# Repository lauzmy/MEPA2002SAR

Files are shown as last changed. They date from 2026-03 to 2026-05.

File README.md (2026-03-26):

# MEPA2002SAR

A ROS 2 + Gazebo Sim workspace that launches simulation, bridges ROS↔Gazebo topics, and runs a small application node that publishes `cmd_vel` for a diff‑drive robot.

## Quickstart
**Prereqs:** Docker Engine with Compose plugin and `make`.

1. Build and start the container:
   - `make build`
   - `make up`
   - `make shell`
2. Build the workspace in the container:
   - `colcon build --cmake-args -DBUILD_TESTING=ON`
   - `source install/setup.sh`
3. Launch the diff‑drive demo:
   - `ros2 launch ros_gz_bringup diff_drive.launch.py`

**Optional GUI tools (RViz/RQt):**
- `make build DESKTOP=1`
- `make x11`
- `make recreate`

## Documentation
- [Architecture](Architecture.md)
- [Setup & Build](Setup.md)
- [Bringup & Launch](Bringup.md)
- [Workspace Layout](Workspace-Layout.md)
- [Packages](Packages.md)
- [Simulation Assets](Simulation-Assets.md)
- [Development Guide](Development-Guide.md)

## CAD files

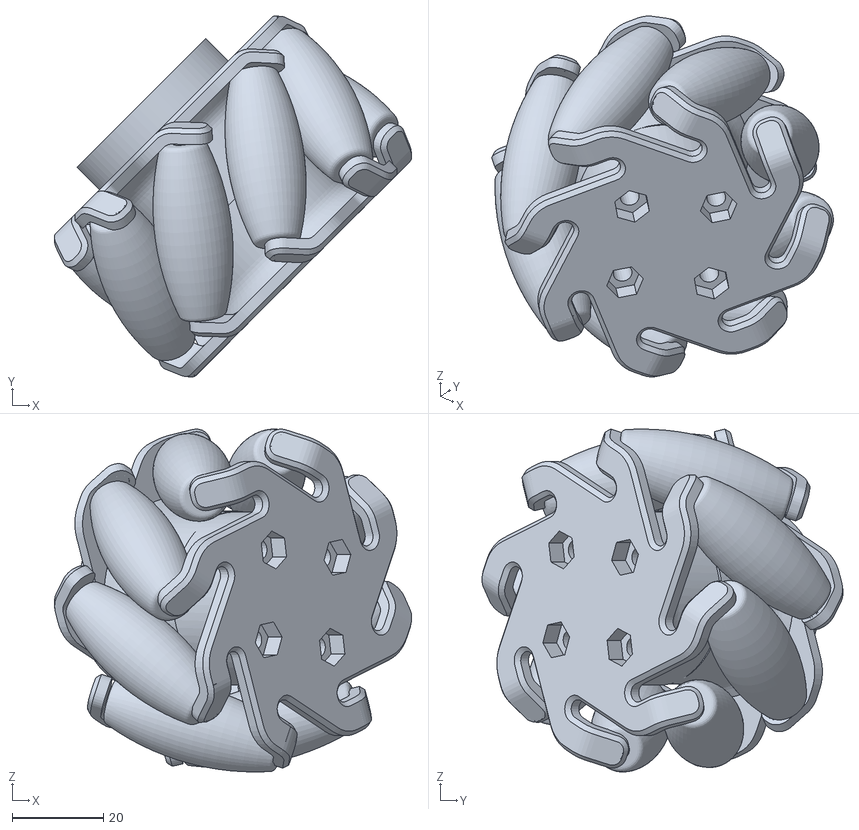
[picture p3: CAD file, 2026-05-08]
src/GregorURDF/meshes/Mecanum-wheel-RR.stl
78.5 x 79.3 x 75.3

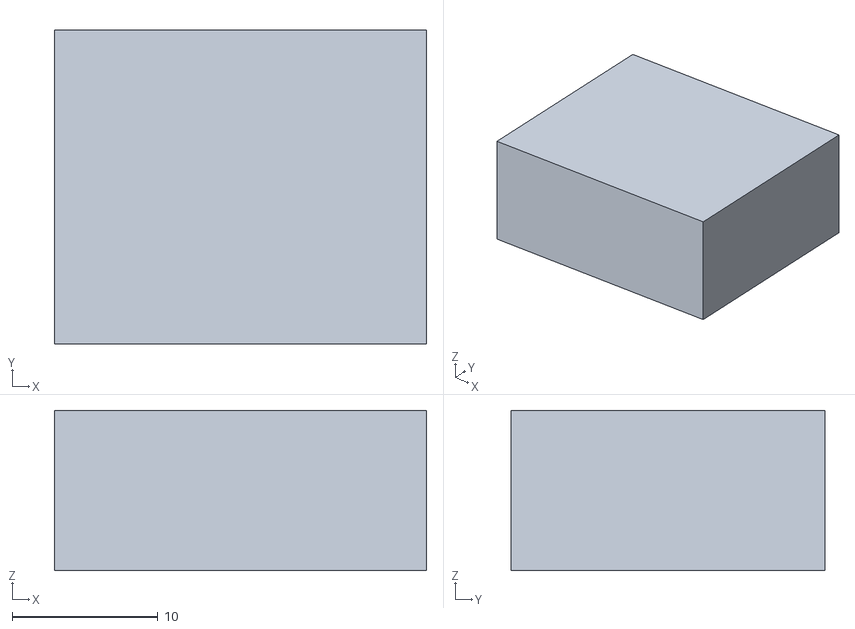
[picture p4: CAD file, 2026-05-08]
src/GregorURDF/meshes/Avstands-sensor-venstre.stl
25.5 x 21.5 x 11.0

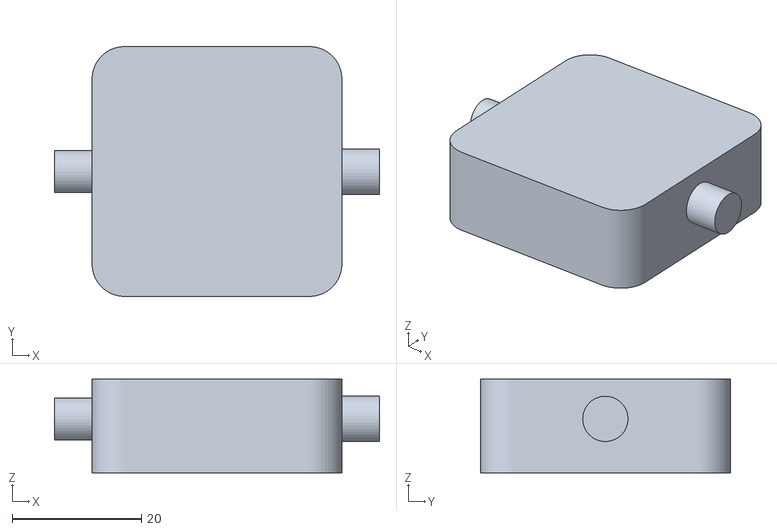
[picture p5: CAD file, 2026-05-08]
src/GregorURDF/meshes/LiDAR-Mount.stl
50.2 x 38.6 x 14.5

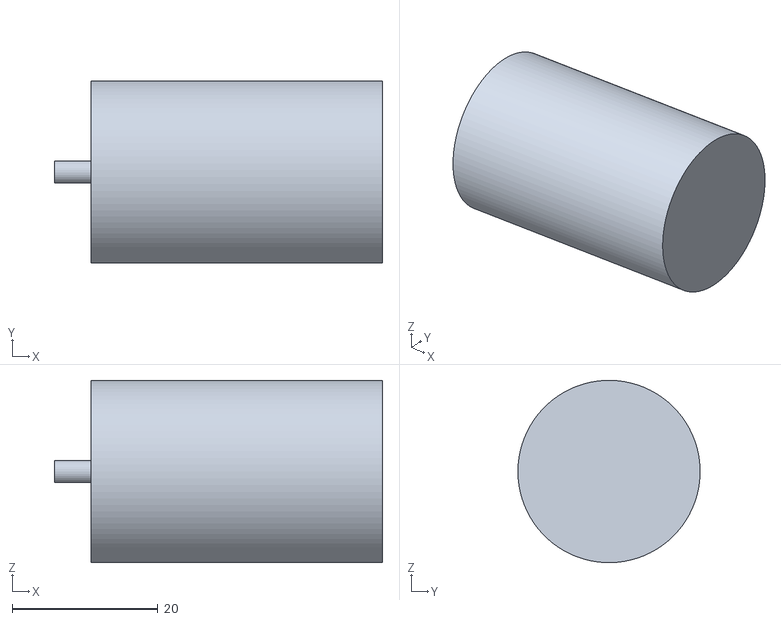
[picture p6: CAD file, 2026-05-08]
src/GregorURDF/meshes/Motor-RR.stl
45.0 x 25.0 x 25.0

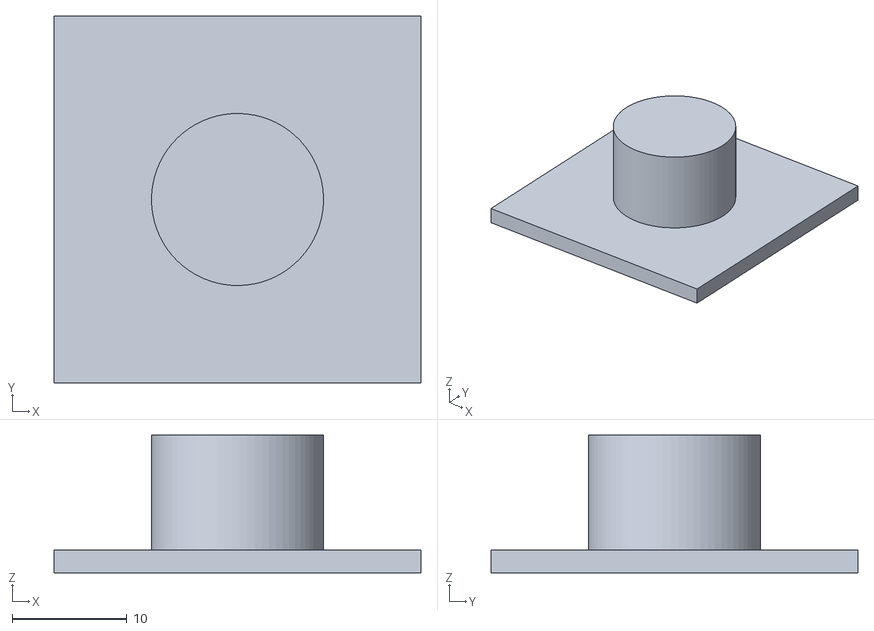
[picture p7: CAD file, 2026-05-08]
src/GregorURDF/meshes/RGB-Camera.stl
32.0 x 32.0 x 12.0

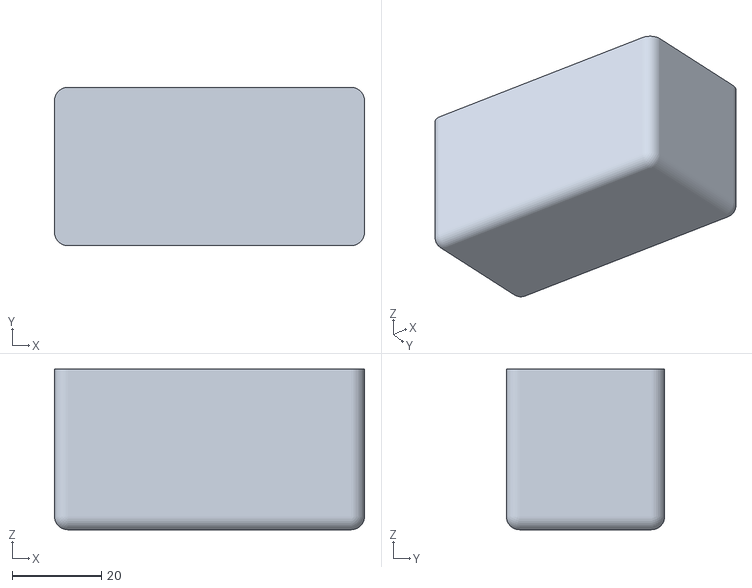
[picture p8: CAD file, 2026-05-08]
src/GregorURDF/meshes/Battery.stl
69.5 x 35.5 x 36.0

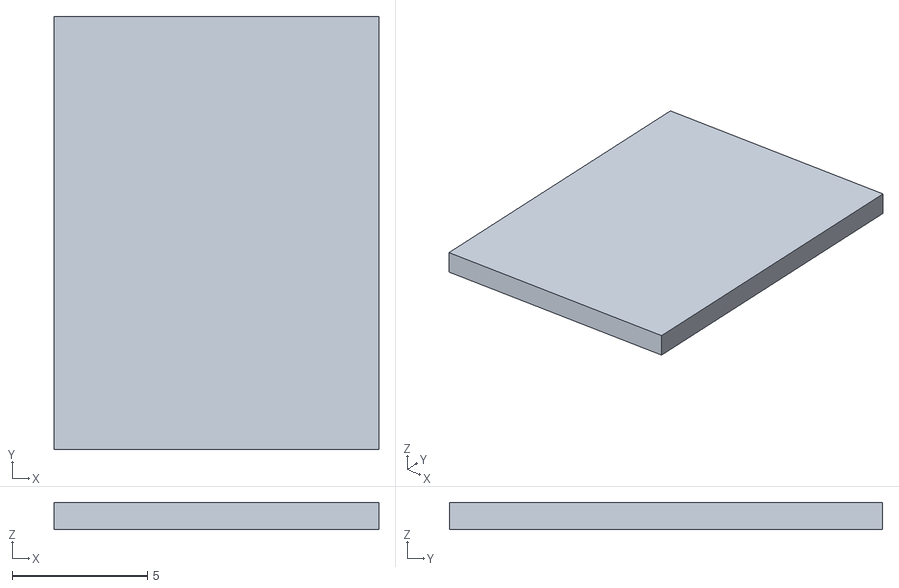
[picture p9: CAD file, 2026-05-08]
src/GregorURDF/meshes/IMU.stl
12.0 x 16.0 x 1.00

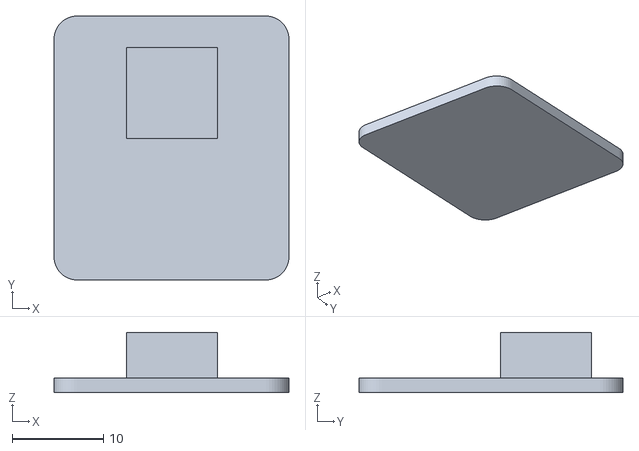
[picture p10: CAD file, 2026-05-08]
src/GregorURDF/meshes/Thermal-camera.stl
25.8 x 28.9 x 6.58

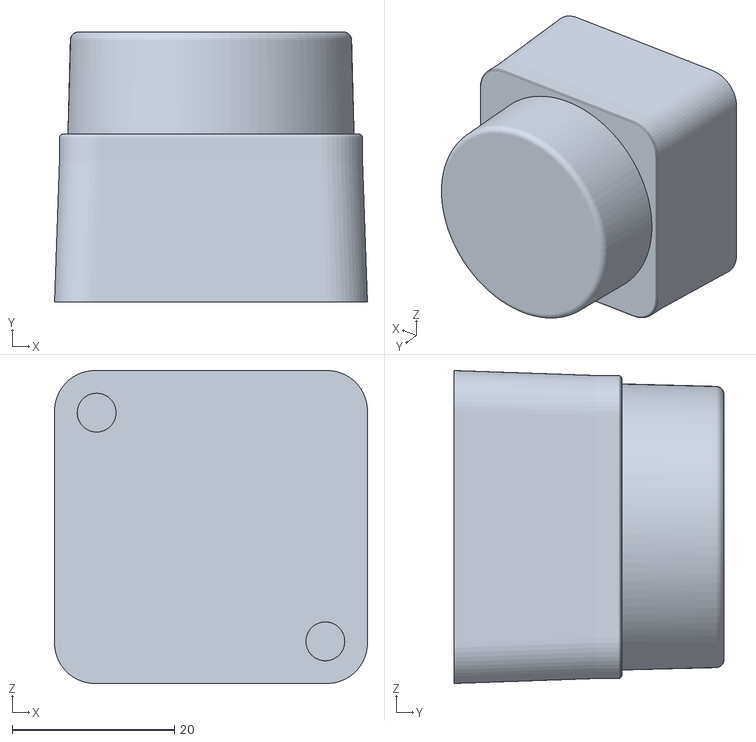
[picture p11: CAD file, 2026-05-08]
src/GregorURDF/meshes/LD06_LiDAR.stl
38.6 x 33.3 x 38.6

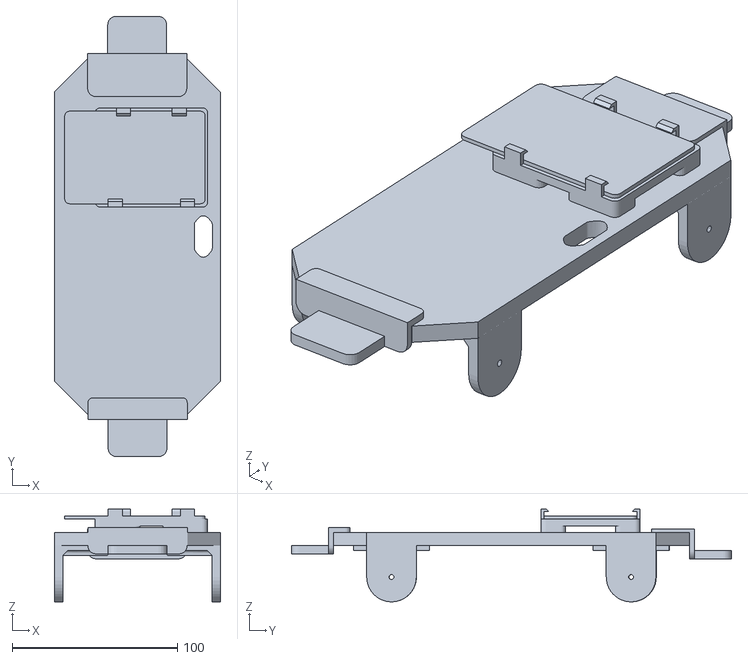
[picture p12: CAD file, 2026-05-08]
src/GregorURDF/meshes/Chassie.stl
100.4 x 266.1 x 56.0

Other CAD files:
src/GregorURDF/meshes/Avstands-sensor-fremme.stl
src/GregorURDF/meshes/Avstands-sensor-bak.stl
src/GregorURDF/meshes/Upper-Level.stl

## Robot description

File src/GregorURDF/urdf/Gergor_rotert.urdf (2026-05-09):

<?xml version='1.0' encoding='utf-8'?>
<robot name="Gergor">
    <link name="Upper-Level">
        <inertial>
            <origin xyz="0.0023967975342630166 -0.0013615270577073536 0.03779211299373483" rpy="0.0 -0.0 0.0" />
            <mass value="0.13651212208139799" />
            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
        </inertial>
        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
    </link>
    <link name="Battery">
        <inertial>
            <origin xyz="4.458219052816403e-09 3.6607721659760727e-09 0.017923845987170874" rpy="0.0 -0.0 0.0" />
            <mass value="0.09697089693767996" />
            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
        </inertial>
        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
    </link>
    <link name="RGB-Camera">
        <inertial>
            <origin xyz="0.003779157752404263 -0.016000000000072616 -0.016000001679936388" rpy="0.0 -0.0 0.0" />
            <mass value="0.00705801985514185" />
            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
        </inertial>
        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
    </link>
    <link name="Avstands-sensor-fremme">
        <inertial>
            <origin xyz="-0.010750000953176712 -0.012750001333232112 -0.0054999999999998566" rpy="0.0 -0.0 0.0" />
            <mass value="0.011156887500000002" />
            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
        </inertial>
        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
    </link>
    <link name="Chassie">
        <inertial>
            <origin xyz="0.0005701965615616624 -0.0010046150242972978 0.0033131328971587404" rpy="0.0 0.0 0.0" />
            <mass value="0.29216485565837275" />
            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
        </inertial>
        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
    </link>
    <link name="Avstands-sensor-bak">
        <inertial>
            <origin xyz="0.010749999869614797 -0.012750001724095177 0.0054999999999998566" rpy="0.0 -0.0 0.0" />
            <mass value="0.011156887500000002" />
            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
        </inertial>
        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
    </link>
    <link name="Thermal-camera">
        <inertial>
            <origin xyz="0.0017759347881090104 -0.012620736087732034 0.01036523496622269" rpy="0.0 -0.0 0.0" />
            <mass value="0.0030870822826619742" />
            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
        </inertial>
        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
    </link>
    <link name="Avstands-sensor-venstre">
        <inertial>
            <origin xyz="0.012750004398614394 -0.010750002155754865 -0.005499997674649775" rpy="0.0 -0.0 0.0" />
            <mass value="0.0111568875" />
            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
        </inertial>
        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
    </link>
    <link name="Motor-FR">
        <inertial>
            <origin xyz="1.7319479184152443e-16 0.02494272447716412 -9.573994930178742e-10" rpy="0.0 -0.0 0.0" />
            <mass value="0.15441088816550527" />
            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
        </inertial>
        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
    </link>
    <link name="LD06_LiDAR">
        <inertial>
            <origin xyz="3.6113848578267493e-09 4.421719479175135e-09 0.015204879071300024" rpy="0.0 -0.0 0.0" />
            <mass value="0.07569091272999597" />
            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
        </inertial>
        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
    </link>
    <link name="IMU">
        <inertial>
            <origin xyz="4.45821904060395e-09 -3.3031442930875345e-09 0.000500000000000096" rpy="0.0 -0.0 0.0" />
            <mass value="0.0003552000152170653" />
            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
        </inertial>
        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
    </link>
    <link name="Mecanum-wheel-FL">
        <inertial>
            <origin xyz="-0.000322364933043513 -0.026544464448392563 0.00017061718757419798" rpy="0.0 -0.0 0.0" />
            <mass value="0.1511892944710378" />
            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
        </inertial>
        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
    </link>
    <link name="LiDAR-Mount">
        <inertial>
            <origin xyz="-0.0010789646894884797 -3.2563265073845916e-05 -2.067058956080295e-05" rpy="9.767397155917488e-50 -0.0 -4.861730685829017e-63" />
            <mass value="0.025423989422360332" />
            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
        </inertial>
        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
    </link>
    <link name="Mecanum-wheel-RL">
        <inertial>
            <origin xyz="-0.0003223649330433842 0.026544460526042205 -0.0001706147432024441" rpy="0.0 -0.0 0.0" />
            <mass value="0.1511892944710378" />
            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
        </inertial>
        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
    </link>
    <link name="Mecanum-wheel-RR">
        <inertial>
            <origin xyz="-0.00032236493304357074 -0.026544461164959225 0.00017061624033781086" rpy="0.0 -0.0 0.0" />
            <mass value="0.1511892944710378" />
            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
        </inertial>
        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
    </link>
    <link name="Mecanum-wheel-FR">
        <inertial>
            <origin xyz="-0.00032236493304340643 0.026544461164959312 -0.00017061407967208453" rpy="0.0 -0.0 0.0" />
            <mass value="0.1511892944710378" />
            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
        </inertial>
        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
    </link>
    <link name="Avstands-sensor-høyre">
        <inertial>
            <origin xyz="-0.012750003968667767 0.01075000376223434 -0.005499999999999901" rpy="0.0 -0.0 0.0" />
            <mass value="0.0111568875" />
            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
        </inertial>
        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
    </link>
    <link name="Motor-RL">
        <inertial>
            <origin xyz="-8.881784197001253e-18 0.02494272511608105 -2.938676235686444e-10" rpy="0.0 -0.0 0.0" />
            <mass value="0.15441088816550527" />
            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
        </inertial>
        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
    </link>
    <link name="Motor-RR">
        <inertial>
            <origin xyz="1.2878587085651815e-16 -0.024942724477164085 -1.203269146543562e-09" rpy="0.0 -0.0 0.0" />
            <mass value="0.15441088816550527" />
            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
        </inertial>
        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
    </link>
    <link name="Motor-FL">
        <inertial>
            <origin xyz="1.1990408665951691e-16 0.02494272119373083 2.1505034375479682e-09" rpy="0.0 -0.0 0.0" />
            <mass value="0.15441088816550527" />
            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
        </inertial>
        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
    </link>
    <joint name="Chassie_Rigid-1" type="fixed">
        <origin xyz="0.00015423000372526423 -0.007561000130385147 -1.4210854715202004e-16" rpy="3.141592653589793 6.1584619237316516e-33 -1.5707963267948966" />
        <parent link="Chassie" />
        <child link="Battery" />
    </joint>
    <joint name="Chassie_Rigid-2" type="fixed">
        <origin xyz="0.00015423000372526423 -0.007561000130385147 0.007999999999999856" rpy="-3.2526065174564526e-19 6.1584619237316516e-33 -1.5707963267948966" />
        <parent link="Chassie" />
        <child link="Upper-Level" />
    </joint>
    <joint name="Upper-Level_Revolute-3" type="continuous">
        <origin xyz="4.479000000000011e-05 -3.5119999999999996e-05 0.08375145" rpy="-1.6930901125533616e-15 -1.5707963267948966 0" />
        <parent link="Upper-Level" />
        <child link="LiDAR-Mount" />
        <axis xyz="9.398538128609942e-32 -0.9999999999999996 -1.6930901125533608e-15" />
    </joint>
    <joint name="LiDAR-Mount_Rigid-4" type="fixed">
        <origin xyz="0.006150000000000003 3.469446951953614e-20 -2.1069999999999702e-05" rpy="1.102916357619544e-47 1.570796326794895 0" />
        <parent link="LiDAR-Mount" />
        <child link="LD06_LiDAR" />
    </joint>
    <joint name="Upper-Level_Rigid-5" type="fixed">
        <origin xyz="0.057249999999999995 -0.03049246 0.056499999999999995" rpy="1.570796326794901 -0.0 0.0" />
        <parent link="Upper-Level" />
        <child link="RGB-Camera" />
    </joint>
    <joint name="Upper-Level_Rigid-6" type="fixed">
        <origin xyz="0.057249999999999995 0.02750754 0.056499999999999995" rpy="1.5707963267948966 -0.0 0.0" />
        <parent link="Upper-Level" />
        <child link="Thermal-camera" />
    </joint>
    <joint name="Upper-Level_Rigid-7" type="fixed">
        <origin xyz="0.0 0.0 0.04035000000000001" rpy="0.0 -0.0 0.0" />
        <parent link="Upper-Level" />
        <child link="IMU" />
    </joint>
    <joint name="Upper-Level_Rigid-8" type="fixed">
        <origin xyz="-0.012 0.085 -0.014802099999999997" rpy="0.0 -0.0 0.0" />
        <parent link="Upper-Level" />
        <child link="Avstands-sensor-venstre" />
    </joint>
    <joint name="Chassie_Rigid-9" type="fixed">
        <origin xyz="0.013000710003725262 -0.14062201013038508 -0.005000000000000142" rpy="-3.2526065174564526e-19 6.1584619237316516e-33 -1.5707963267948966" />
        <parent link="Chassie" />
        <child link="Avstands-sensor-fremme" />
    </joint>
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

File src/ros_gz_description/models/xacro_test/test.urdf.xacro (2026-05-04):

<?xml version="1.0"?>
<robot name="rrbot" xmlns:xacro="http://www.ros.org/wiki/xacro" xmlns:gz="http://gazebosim.org/schema">


  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
  <xacro:property name="pi_const" value="3.141592653589793"/>

  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
  <xacro:property name="a" value="0.22"/>
  <xacro:property name="b" value="0.1"/>
  <xacro:property name="c" value="0.1"/>

  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
  <xacro:property name="r" value="0.0375"/>
  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
  <xacro:property name="d" value="0.043"/>


  <xacro:property name="s1" value="${b/2+r}"/>
  <xacro:property name="s2" value="${2*r}"/>
  <xacro:property name="s3" value="${2*r}"/>
  <xacro:property name="s4" value="${c/2+d/2}"/>
  <xacro:property name="s5" value="${b/2}"/>


  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
  <xacro:property name="d1" value="2710.0"/>
  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
  <xacro:property name="d2" value="2710.0"/>
  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
  <xacro:property name="d3" value="2710.0"/>

  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
  <xacro:property name="m1" value="${d1*a*b*c}"/>
  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
  <xacro:property name="m2" value="${d2*pi_const*r*r*d}"/>
  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
  <xacro:property name="m3" value="${d3*4/3*pi_const*r*r*r}"/>

  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
  <xacro:property name="Ix_body" value="${m1*(b*b+c*c)/12}"/>
  <xacro:property name="Iy_body" value="${m1*(a*a+c*c)/12}"/>
  <xacro:property name="Iz_body" value="${m1*(a*a+b*b)/12}"/>

  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
  <xacro:property name="Iz_wheel" value="${m2*r*r/2}"/>
  <xacro:property name="I_wheel" value="${m2*(3*r*r + d*d)/12}"/>



  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
  <xacro:macro name="inertial_body">
    <inertial>
    <origin rpy=" 0 0 0" xyz="0 0 ${s1}"/>
    <mass value="${m1}"/>
    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
    </inertial>
  </xacro:macro>

  <xacro:macro name="inertial_wheel">
    <inertial>
    <origin rpy="1.570795 0 0" xyz="0 0 0"/>
    <mass value="${m2}"/>
    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
    </inertial>
  </xacro:macro>


  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

  <link name="base_footprint"/>
  
  <joint name="body_link_joint" type="fixed">
    <parent link="base_footprint"/>
    <child link="body_link"/>
  </joint>


  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
  <link name="body_link">
    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  

    <xacro:inertial_body/>
  </link>

  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
  <joint name="rear_right_wheel_joint" type="continuous">
    <parent link="body_link"/>
    <child link="rear_right_wheel_link"/>
    <origin xyz="${-s2} ${-s4} ${r}" rpy="0 0 0"/>
    <axis xyz="0 1 0"/>
    <limit effort="50000" velocity="10"/>
    <dynamics damping="1.0" friction="1.0"/>
  </joint>

  <link name="rear_right_wheel_link">
    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

    <xacro:inertial_wheel/>
  </link>

  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
  <joint name="rear_left_wheel_joint" type="continuous">
    <parent link="body_link"/>
    <child link="rear_left_wheel_link"/>
    <origin xyz="${-s2} ${s4} ${r}" rpy="0 0 0"/>
    <axis xyz="0 1 0"/>
    <limit effort="50000" velocity="10"/>
    <dynamics damping="1.0" friction="1.0"/>
  </joint>

  <link name="rear_left_wheel_link">
    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

    <xacro:inertial_wheel/>
  </link>

  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
  <joint name="front_right_wheel_joint" type="continuous">
    <parent link="body_link"/>
    <child link="front_right_wheel_link"/>
    <origin xyz="${s2} ${-s4} ${r}" rpy="0 0 0"/>
    <axis xyz="0 1 0"/>
    <limit effort="50000" velocity="10"/>
    <dynamics damping="1.0" friction="1.0"/>
  </joint>

  <link name="front_right_wheel_link">
    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

    <xacro:inertial_wheel/>
  </link>

  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
  <joint name="front_left_wheel_joint" type="continuous">
    <parent link="body_link"/>
    <child link="front_left_wheel_link"/>
    <origin xyz="${s2} ${s4} ${r}" rpy="0 0 0"/>
    <axis xyz="0 1 0"/>
    <limit effort="50000" velocity="10"/>
    <dynamics damping="1.0" friction="1.0"/>
  </joint>

  <link name="front_left_wheel_link">
    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

    <xacro:inertial_wheel/>
  </link>


  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
  <joint name="lidar_joint" type="revolute">
    <parent link="body_link"/>
    <child link="lidar_hinge_link"/>
    <origin xyz="0 0 ${s1+s5}" rpy="0 0 0"/>
    <axis xyz="0 1 0"/> 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
    <limit lower="-0.785398" upper="0.785398" effort="10.0" velocity="5.0"/> 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
    <dynamics damping="0.1" friction="0.1"/>
  </joint>

  <link name="lidar_hinge_link">
    <inertial>
      <mass value="0.05"/>
      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
    </inertial>
  </link>
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

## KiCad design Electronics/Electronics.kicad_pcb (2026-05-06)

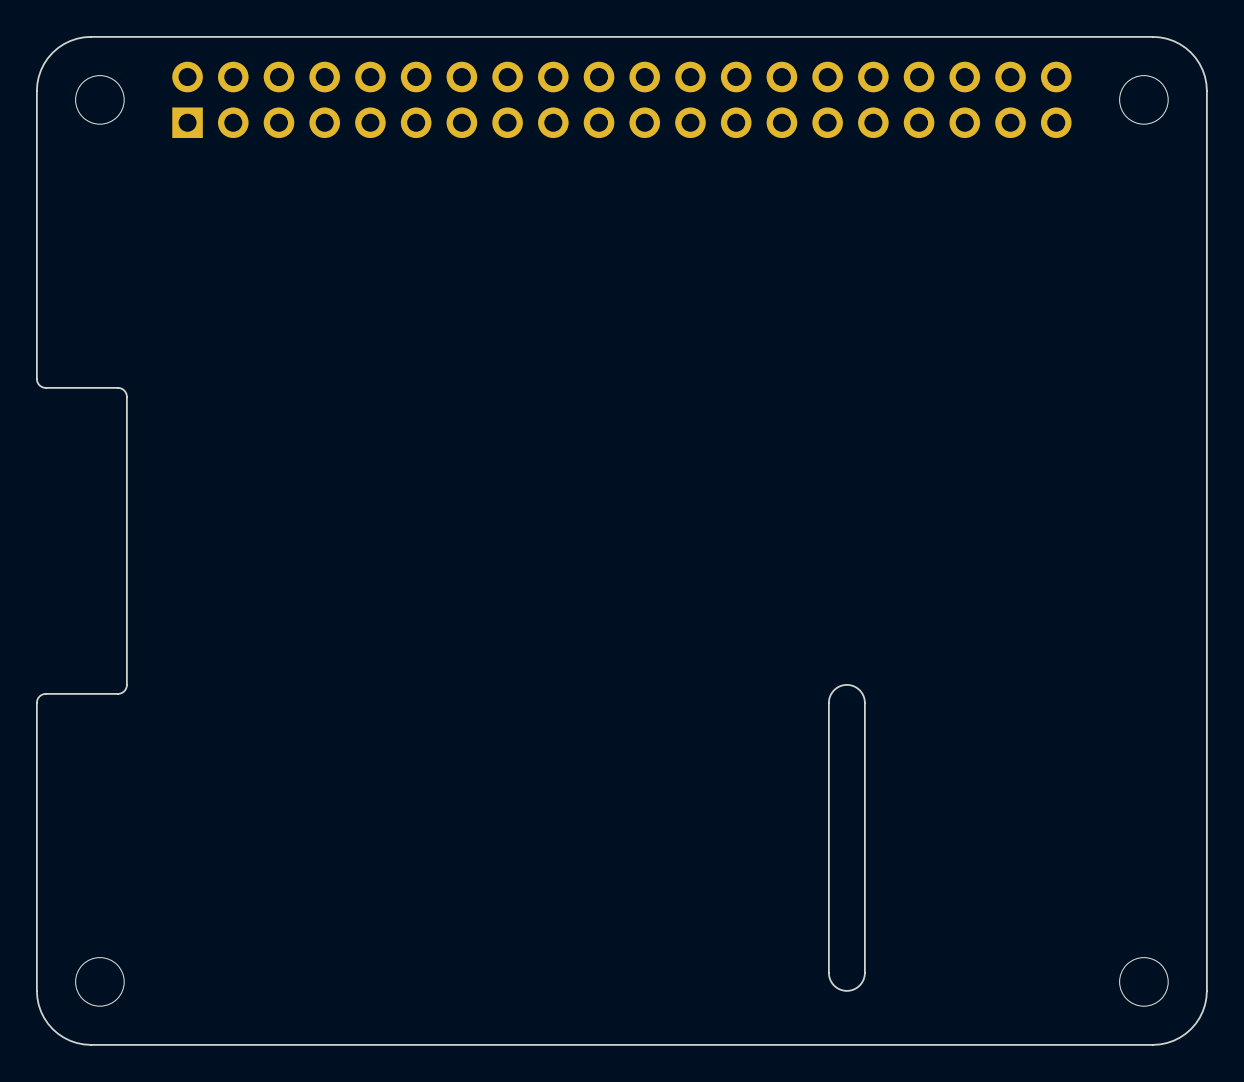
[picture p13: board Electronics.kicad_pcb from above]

Board: 2 copper layers, 65.0 x 56.0 mm, 5 parts (1 on the bottom side), 3 nets, no tracks yet.

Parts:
J1: GPIO; PinSocket_2x20_P2.54mm_Vertical
MH1, MH2, MH3, MH4: MountingHole_2.7mm_M2.5

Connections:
+3V3: J1.1, J1.17
+5V: J1.2, J1.4
GND: J1.6, J1.9, J1.14, J1.20, J1.25, J1.30, J1.34, J1.39

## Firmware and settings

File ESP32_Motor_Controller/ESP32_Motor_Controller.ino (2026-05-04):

/*
 * ESP32 Motor Controller
 *
 * Single-loop architecture.
 * ISRs write volatile period data; loop() reads, filters, and dispatches.
 *
 * Protocol (8 bytes, unchanged from v1):
 *   Command:  [START=0x55][CMD][M1_SPD][M2_SPD][M3_SPD][M4_SPD][DIRS][CRC8]
 *   Response: [START=0x55][STATUS][M1_RPM][M2_RPM][M3_RPM][M4_RPM][VBATT][CRC8]
 *
 *   CRC-8/MAXIM covers bytes 0-6.
 *   DIRS = [0][0][0][0][M4_DIR][M3_DIR][M2_DIR][M1_DIR]
 *   VBATT = battery voltage scaled 0-255 (0-16V)
 *
 * Commands:
 *   0x01: Set all motors (speed + direction)
 *   0x02: Stop all motors
 *   0xFF: Ping / request telemetry
 *
 * Status:
 *   0x00: OK
 *   0x01: Invalid command
 */

#include <HardwareSerial.h>

// ============================================================================
// CONFIGURATION
// ============================================================================

// UART — using UART0 (USB via onboard USB-to-serial chip)
// Switch UART_USE_USB to 0 and set UART_TX_PIN/RX_PIN to use hardware pins instead.
#define UART_USE_USB  1          // 1 = Serial (USB/UART0), 0 = UART2 (pins 16/17)
#define UART_TX_PIN   17         // only used when UART_USE_USB = 0
#define UART_RX_PIN   16         // only used when UART_USE_USB = 0
#define UART_BAUDRATE 921600

// Battery ADC
#define VOLTAGE_PIN           13
#define VOLTAGE_DIVIDER_RATIO 0.17543859649123f  // 100k / (470k + 100k)
#define ADC_VREF              3.3f
#define ADC_CAL_FACTOR        (16.0f / 10.0f)    // empirical non-linearity correction

// Motor PWM
#define PWM_FREQ       20000
#define PWM_RESOLUTION 10      // 10-bit → 0-1023
#define PWM_MAX        1023

// Encoder
#define PPR                 270
#define FEEDBACK_TIMEOUT_US 6000                    // RPM → 0 if no pulse within this window
#define DEBOUNCE_MIN_US     50                      // ignore pulses shorter than this
#define DEBOUNCE_MAX_US     ((uint32_t)(FEEDBACK_TIMEOUT_US * 4))

// EMA filter (0.0–1.0: higher = faster response, more noise)
#define EMA_ALPHA 0.4f

// Comms watchdog — stop motors if no valid packet received within this window.
// Must be set to at least 3-5× your control loop's inter-packet interval.
// e.g. 100 Hz loop (10 ms/packet) → 50 ms minimum; 50 Hz (20 ms) → 100 ms.
// Too short and the watchdog fires between every packet, keeping motors stopped.
#define WATCHDOG_MS 200

// Protocol
#define PACKET_SIZE 8
#define START_BYTE  0x55

// Commands
#define CMD_SET_ALL  0x01
#define CMD_STOP_ALL 0x02
#define CMD_PING     0xFF

// Status bytes
#define STATUS_OK           0x00
#define STATUS_INVALID_CMD  0x01
#define STATUS_CHECKSUM_ERR 0x02

// ============================================================================
// MOTOR PIN MAP
// ============================================================================

struct MotorPins {
  int  dir_pin;
  int  pwm_pin;
  int  sig_pin;
  bool invert_dir;
};

const MotorPins MOTOR_CONFIG[4] = {
  {21, 22, 23, true },  // M1
  {18,  2, 19, false},  // M2
  {14, 12, 27, false},  // M3
  {25, 26, 33, true }   // M4
};

// ============================================================================
// MOTOR STATE
// ============================================================================

struct MotorState {
  volatile uint32_t last_rise_us;  // written by ISR
  volatile uint32_t period_us;     // written by ISR (latest raw period)
  float    ema_period_us;          // EMA-filtered period  (loop() only)
  uint8_t  rpm;                    // computed RPM         (loop() only)
};

MotorState motors[4];

// ============================================================================
// ENCODER ISRs
// No locks needed — loop() is the sole reader of ema_period_us / rpm,
// and 32-bit aligned volatile reads are atomic on Xtensa LX6.
// ============================================================================

void IRAM_ATTR motorISR0() {
  uint32_t now = micros();
  uint32_t p = now - motors[0].last_rise_us;
  if (p > DEBOUNCE_MIN_US && p < DEBOUNCE_MAX_US) motors[0].period_us = p;
  motors[0].last_rise_us = now;
}

void IRAM_ATTR motorISR1() {
  uint32_t now = micros();
  uint32_t p = now - motors[1].last_rise_us;
  if (p > DEBOUNCE_MIN_US && p < DEBOUNCE_MAX_US) motors[1].period_us = p;
  motors[1].last_rise_us = now;
}

void IRAM_ATTR motorISR2() {
  uint32_t now = micros();
  uint32_t p = now - motors[2].last_rise_us;
  if (p > DEBOUNCE_MIN_US && p < DEBOUNCE_MAX_US) motors[2].period_us = p;
  motors[2].last_rise_us = now;
}

void IRAM_ATTR motorISR3() {
  uint32_t now = micros();
  uint32_t p = now - motors[3].last_rise_us;
  if (p > DEBOUNCE_MIN_US && p < DEBOUNCE_MAX_US) motors[3].period_us = p;
  motors[3].last_rise_us = now;
}

// ============================================================================
// MOTOR CONTROL
// ============================================================================

void setMotor(int id, int speed, bool dir) {
  speed = constrain(speed, 0, 255);
  digitalWrite(MOTOR_CONFIG[id].dir_pin, dir ^ MOTOR_CONFIG[id].invert_dir);
  int duty = ((255 - speed) * PWM_MAX) / 255;  // inverted: 0 speed → full PWM_MAX (stopped)
  ledcWrite(MOTOR_CONFIG[id].pwm_pin, duty);
}

void stopAllMotors() {
  for (int i = 0; i < 4; i++) setMotor(i, 0, 0);
}

// ============================================================================
// CRC-8/MAXIM (polynomial 0x31)
// ============================================================================

uint8_t crc8(const uint8_t* data, int len) {
  uint8_t crc = 0x00;
  for (int i = 0; i < len; i++) {
    crc ^= data[i];
    for (int j = 0; j < 8; j++)
      crc = (crc & 0x80) ? (crc << 1) ^ 0x31 : (crc << 1);
  }
  return crc;
}

// ============================================================================
// BATTERY ADC — 4-sample oversampling + voltage divider + calibration
// ============================================================================

uint8_t readBattery() {
  int sum = 0;
  for (int i = 0; i < 4; i++) sum += analogRead(VOLTAGE_PIN);
  float v_meas = ((sum / 4) / 4095.0f) * ADC_VREF;
  float v_batt = (v_meas / VOLTAGE_DIVIDER_RATIO) * ADC_CAL_FACTOR;
  return (uint8_t)constrain((int)(v_batt * (255.0f / 16.0f)), 0, 255);
}

// ============================================================================
// RPM UPDATE — EMA filter applied every loop() iteration
// ============================================================================

void updateRPM() {
  uint32_t now = micros();
  for (int i = 0; i < 4; i++) {
    uint32_t last_rise = motors[i].last_rise_us;  // volatile 32-bit: atomic on LX6
    uint32_t period    = motors[i].period_us;

    if (period == 0 || (now - last_rise) > FEEDBACK_TIMEOUT_US) {
      motors[i].ema_period_us = 0.0f;
      motors[i].rpm = 0;
    } else {
      if (motors[i].ema_period_us == 0.0f) {
        motors[i].ema_period_us = (float)period;  // seed filter on first pulse
      } else {
        motors[i].ema_period_us = EMA_ALPHA * (float)period
                                + (1.0f - EMA_ALPHA) * motors[i].ema_period_us;
      }
      float rpm_f = 60000000.0f / (motors[i].ema_period_us * PPR);
      motors[i].rpm = (uint8_t)constrain((int)rpm_f, 0, 255);
    }
  }
}

// ============================================================================
// UART STATE MACHINE
// ============================================================================

// Battery reading cached here and refreshed every BATTERY_UPDATE_MS milliseconds.
// Keeps readBattery() (4x blocking analogRead) off the response hot-path.
#define BATTERY_UPDATE_MS 5
static uint8_t  cached_battery     = 0;
static uint32_t battery_next_ms    = 0;

// Comms serial — Serial (UART0) for USB, or UART2 for hardware pins
#if UART_USE_USB
  #define UARTComm Serial
#else
  HardwareSerial UARTComm(2);
#endif

enum UartState { WAIT_START, COLLECT };
static UartState uart_state = WAIT_START;
static uint8_t   rx_buf[PACKET_SIZE];
static int       rx_count = 0;

// Watchdog state
static uint32_t last_valid_ms  = 0;
static bool     watchdog_fired = false;

void sendResponse(uint8_t status) {
  uint8_t resp[PACKET_SIZE];
  resp[0] = START_BYTE;
  resp[1] = status;
  for (int i = 0; i < 4; i++) resp[2 + i] = motors[i].rpm;
  resp[6] = cached_battery;   // updated every ~5 ms in loop(); never blocks
  resp[7] = crc8(resp, PACKET_SIZE - 1);
  UARTComm.write(resp, PACKET_SIZE);
}

void runUART() {
  while (UARTComm.available()) {
    uint8_t b = (uint8_t)UARTComm.read();

    if (uart_state == WAIT_START) {
      if (b != START_BYTE) continue;     // skip until framed
      rx_buf[0]  = b;
      rx_count   = 1;
      uart_state = COLLECT;
      continue;
    }

    // COLLECT state
    rx_buf[rx_count++] = b;

    if (rx_count < PACKET_SIZE) continue;  // not yet a full packet

    // ── Full packet received ──────────────────────────────────────────────
    uart_state = WAIT_START;
    rx_count   = 0;

    // Validate CRC
    if (crc8(rx_buf, PACKET_SIZE - 1) != rx_buf[PACKET_SIZE - 1]) {
      // Flush anything still in the FIFO before responding.
      // Without this, a 0x55 byte inside the corrupted packet (or the next
      // in-flight packet) would be picked up as a false start byte, causing
      // the *next* packet to be misaligned and also fail CRC — cascading errors.
      while (UARTComm.available()) UARTComm.read();
      uart_state = WAIT_START;
      sendResponse(STATUS_CHECKSUM_ERR);
      break;
    }

    // Valid packet
    last_valid_ms  = millis();
    watchdog_fired = false;

    uint8_t cmd  = rx_buf[1];
    uint8_t stat = STATUS_OK;

    switch (cmd) {
      case CMD_SET_ALL: {
        uint8_t dirs = rx_buf[6];
        setMotor(0, rx_buf[2],  dirs        & 0x01);
        setMotor(1, rx_buf[3], (dirs >> 1)  & 0x01);
        setMotor(2, rx_buf[4], (dirs >> 2)  & 0x01);
        setMotor(3, rx_buf[5], (dirs >> 3)  & 0x01);
        break;
      }
      case CMD_STOP_ALL:
        stopAllMotors();
        break;
      case CMD_PING:
        break;  // just respond with current telemetry
      default:
        stat = STATUS_INVALID_CMD;
        break;
    }

    sendResponse(stat);
    break;  // one packet per drain pass — keep latency predictable
  }
}

// ============================================================================
// SETUP
// ============================================================================

void setup() {
  // Initialise motors
  for (int i = 0; i < 4; i++) {
    motors[i] = {0, 0, 0.0f, 0};
    pinMode(MOTOR_CONFIG[i].dir_pin, OUTPUT);
    pinMode(MOTOR_CONFIG[i].sig_pin, INPUT_PULLUP);
    digitalWrite(MOTOR_CONFIG[i].dir_pin, LOW);
    ledcAttach(MOTOR_CONFIG[i].pwm_pin, PWM_FREQ, PWM_RESOLUTION);
    ledcWrite(MOTOR_CONFIG[i].pwm_pin, PWM_MAX);  // stopped
  }

  // Attach encoder ISRs
  attachInterrupt(digitalPinToInterrupt(MOTOR_CONFIG[0].sig_pin), motorISR0, RISING);
  attachInterrupt(digitalPinToInterrupt(MOTOR_CONFIG[1].sig_pin), motorISR1, RISING);
  attachInterrupt(digitalPinToInterrupt(MOTOR_CONFIG[2].sig_pin), motorISR2, RISING);
  attachInterrupt(digitalPinToInterrupt(MOTOR_CONFIG[3].sig_pin), motorISR3, RISING);

  // ADC
  analogReadResolution(12);
  analogSetAttenuation(ADC_ATTENDB_MAX);  // 0-3.3V range

  // UART init — wake on first byte, flush partial packets after ~174 µs idle
#if UART_USE_USB
  UARTComm.begin(UART_BAUDRATE);  // USB: pins fixed by hardware
#else
  UARTComm.begin(UART_BAUDRATE, SERIAL_8N1, UART_RX_PIN, UART_TX_PIN);
#endif
  UARTComm.setRxFIFOFull(1);
  UARTComm.setRxTimeout(2);

  last_valid_ms = millis();
}

// ============================================================================
// MAIN LOOP
// ============================================================================

void loop() {
  // 1. Update EMA-filtered RPM from latest ISR data
  updateRPM();

  // 2. Drain UART and dispatch any complete packet
  runUART();

  // 3. Comms watchdog — stop motors after 5 ms of silence
  if (!watchdog_fired && (millis() - last_valid_ms > WATCHDOG_MS)) {
    stopAllMotors();
    watchdog_fired = true;
  }

  // 4. Refresh battery cache every BATTERY_UPDATE_MS — time-based so the loop
  //    can run as fast as possible without hammering the ADC.
  uint32_t now_ms = millis();
  if (now_ms >= battery_next_ms) {
    battery_next_ms = now_ms + BATTERY_UPDATE_MS;
    cached_battery = readBattery();
  }
}

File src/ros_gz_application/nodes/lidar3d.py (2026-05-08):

#!/usr/bin/env python3
"""3D LiDAR node: tilt sweep + UART angle feedback + cloud assembly.

This single node owns everything related to turning the 2-D LD06
LaserScan into a 3-D PointCloud2 stream suitable for MOLA-LO:

    * Drives the tilt servo with a continuous triangle sweep (no
      stepping, no settle/hold gating).
    * Reads the *measured* tilt angle from an ESP32 over UART
      (/dev/ttyAMA1, 921600 8N1, framed binary packets).  Because we
      know the real angle at any time we don't have to trust the servo
      command.
    * For every incoming /scan we look up the measured tilt angle at
      each beam's timestamp, rotate the beam into the fixed mount
      frame, and publish the result as a PointCloud2 with a per-point
      `time` channel (the layout MOLA-LO / FAST-LIO expect).
    * Publishes /lidar_joint_states (the measured angle) so RViz and
      robot_state_publisher show the laser tilted correctly.

Frames
------
    body_link              fixed mount of the tilt mechanism
      └── lidar_joint      revolute (about Y)  -- angle from UART
            └── lidar_hinge_link
                  └── (fixed +Z offset)
                        └── laser              LD06 frame (/scan)

Output cloud is published in `body_link` with the tilt + Z offset
already baked into the points -- consumers don't need TF for the tilt.

UART packet (little-endian, 7 bytes)
------------------------------------
    [0]   sync     0xAA
    [1]   seq      uint8
    [2..3] angle   int16, centi-degrees (0..27000 spans the pot)
    [4..5] wiper   uint16, millivolts (ignored here)
    [6]   crc8     poly 0x07, init 0x00, over bytes 1..5
"""

from __future__ import annotations

import math
import threading
from collections import deque
from typing import Deque, Tuple

import numpy as np
import rclpy
import serial
from rclpy.node import Node
from rclpy.qos import QoSHistoryPolicy, QoSProfile, QoSReliabilityPolicy

from sensor_msgs.msg import JointState, LaserScan, PointCloud2, PointField
from std_msgs.msg import Float64, Header


# ── PointCloud2 layout (x y z intensity time ring) ───────────────────
# `ring` is constant 0 (single tilted ring), but FAST-LIO / LIO-SAM /
# Point-LIO all expect the field to exist -- it costs 2 bytes/point and
# guarantees portability.
_FIELDS = [
    PointField(name='x',         offset=0,  datatype=PointField.FLOAT32, count=1),
    PointField(name='y',         offset=4,  datatype=PointField.FLOAT32, count=1),
    PointField(name='z',         offset=8,  datatype=PointField.FLOAT32, count=1),
    PointField(name='intensity', offset=12, datatype=PointField.FLOAT32, count=1),
    PointField(name='time',      offset=16, datatype=PointField.FLOAT32, count=1),
    PointField(name='ring',      offset=20, datatype=PointField.UINT16,  count=1),
]
_POINT_STEP = 24  # 5*float32 + uint16 + 2 bytes pad


def _crc8(buf: bytes) -> int:
    """CRC8 poly 0x07, init 0x00 -- matches the ESP32 firmware."""
    c = 0
    for b in buf:
        c ^= b
        for _ in range(8):
            c = ((c << 1) ^ 0x07) & 0xFF if c & 0x80 else (c << 1) & 0xFF
    return c


# ── Angle history: thread-safe ring buffer of (t_seconds, angle_rad) ───────
class AngleHistory:
    """Tiny lock-protected buffer for interpolating the measured tilt."""

    def __init__(self, capacity: int = 4096):
        self._buf: Deque[Tuple[float, float]] = deque(maxlen=capacity)
        self._lock = threading.Lock()

    def push(self, t: float, angle_rad: float) -> None:
        with self._lock:
            self._buf.append((t, angle_rad))

    def latest(self) -> Tuple[float, float] | None:
        with self._lock:
            return self._buf[-1] if self._buf else None

    def snapshot(self) -> Tuple[np.ndarray, np.ndarray] | None:
        """Copy the buffer out as two parallel numpy arrays (t, angle)."""
        with self._lock:
            if not self._buf:
                return None
            arr = np.fromiter(
                (v for pair in self._buf for v in pair),
                dtype=np.float64,
                count=2 * len(self._buf),
            ).reshape(-1, 2)
        return arr[:, 0], arr[:, 1]


# ── UART reader thread ─────────────────────────────────────────────────────
class UartAngleReader(threading.Thread):
    """Background thread: reads framed packets, pushes (t, angle) samples."""

    SYNC = 0xAA
    PACKET_LEN = 7

    def __init__(self, port: str, baud: int, history: AngleHistory,
                 angle_offset_rad: float, invert: bool, clock, logger):
        super().__init__(daemon=True)
        self._port_name = port
        self._baud = baud
        self._history = history
        self._offset = angle_offset_rad
        self._sign = -1.0 if invert else 1.0
        self._clock = clock
        self._log = logger
        self._stop = threading.Event()
        self._ser: serial.Serial | None = None

    def stop(self) -> None:
        self._stop.set()
        if self._ser is not None:
            try:
                self._ser.close()
            except Exception:  # noqa: BLE001
                pass

    def run(self) -> None:
        try:
            self._ser = serial.Serial(self._port_name, self._baud, timeout=0.1)
        except Exception as e:  # noqa: BLE001
            self._log.error(f'UART open failed ({self._port_name}): {e}')
            return
        self._log.info(f'UART open: {self._port_name} @ {self._baud}')

        buf = bytearray()
        while not self._stop.is_set():
            try:
                chunk = self._ser.read(64)
            except Exception as e:  # noqa: BLE001
                self._log.warn(f'UART read error: {e}')
                continue
            if not chunk:
                continue
            buf.extend(chunk)
            self._consume(buf)

    def _consume(self, buf: bytearray) -> None:
        """Pull every complete, CRC-valid packet out of `buf`."""
        while len(buf) >= self.PACKET_LEN:
            if buf[0] != self.SYNC:
                del buf[0]
                continue
            packet = bytes(buf[:self.PACKET_LEN])
            if _crc8(packet[1:6]) != packet[6]:
                # Bad CRC -- drop the sync byte and resync.
                del buf[0]
                continue
            angle_cdeg = int.from_bytes(packet[2:4], 'little', signed=True)
            angle_rad = self._sign * math.radians(angle_cdeg / 100.0) + self._offset
            t_now = self._clock.now().nanoseconds * 1e-9
            self._history.push(t_now, angle_rad)
            del buf[:self.PACKET_LEN]


# ── Tilt sweep waveform ────────────────────────────────────────────────────
def _triangle(t: float, period: float, lo: float, hi: float) -> float:
    """Continuous triangle wave between `lo` and `hi` with period `period`."""
    if period <= 0.0:
        return 0.5 * (lo + hi)
    phase = (t % period) / period           # 0 .. 1
    tri = 1.0 - abs(2.0 * phase - 1.0)      # 0 .. 1 .. 0
    return lo + tri * (hi - lo)
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

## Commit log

2026-02-12 added ros_gz examle structure
    [diff_drive.sdf, model.sdf]
2026-03-26 Gazebo med slam_toolbox og nav2
    [test.urdf.xacro, test_xacro.sdf.xacro]
2026-04-24 Laget gregor leunch-fil. Lagt til kalmanfilter, og lidar sweep_node
    [test.urdf.xacro]
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2026-04-29 Remove rrbot and diff_drive configurations and models; add YOLO node to test_xacro launch
    [diff_drive.sdf, model.sdf, test_xacro.sdf.xacro]
2026-04-30 Update serial port for Lidar configuration and remove unused ldlidar subproject
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2026-05-02 Endret til uart1 i alloc og lagt til en laster_tf_node
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2026-05-04 possibly quick fixed i2c permissions
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2026-05-04 bytta lidar_link til laser
    [test.urdf.xacro]
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2026-05-04 flipped some + and -
    [allocator.py]
2026-05-04 flipped some more + and -
    [allocator.py]
2026-05-04 flipped even more + and - (in odom)
    [allocator.py]
2026-05-05 fixed odom kinematics
2026-05-05 Lagde node for å håndtere rå data fra termo data, og la til launch fil
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2026-05-05 grant access to hardware PWM sysfs in entrypoint script
2026-05-05 fixed pwm permissions?
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2026-05-06 prøver å snu imu i xacro
    [test.urdf.xacro]
2026-05-06 var ikke det
    [test.urdf.xacro]
2026-05-06 wiring diagram
    [Electronics.kicad_pcb, Electronics.kicad_sch]
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2026-05-06 Fix rotation matrix for Y-axis tilt in laser assembly
2026-05-06 Fix rotation matrix calculations in laser assembler and clarify time handling in lidar sweeper
2026-05-06 Adjust servo lag parameter in lidar launch file to reduce cloud shearing
2026-05-06 Increase scans per sweep in lidar3d_test.launch.py for improved data resolution
2026-05-06 Increase servo lag parameter in lidar3d_test.launch.py to reduce cloud shearing
2026-05-06 Fix rotation matrix in laser assembler and reset servo lag parameter in lidar3d_test.launch.py
2026-05-06 Add servo lag parameter to lidar3d_test.launch.py for improved tuning
2026-05-06 Enhance laser assembler with JointState integration for angle interpolation and automatic servo lag correction
2026-05-06 Implement PID control for auto lag calibration in laser assembler
2026-05-06 Refine PID parameters and enhance floor detection for auto lag calibration in laser assembler
2026-05-06 Refactor Lidar Sweeper to use step-and-settle control for servo
    - Updated the LidarSweeper node to implement a step-and-settle approach for controlling the LD06 2D LiDAR tilt angle.
    - Introduced parameters for minimum and maximum angles, step size, settle time, and hold time.
    - Replaced continuous sweeping with discrete angle commands followed by wait periods to ensure stable scans.
    - Added new topics for joint states and hold state to facilitate synchronization with the assembler.
    - Updated launch files to reflect new parameters and removed obsolete ones.
    - Added dependency on tf2_ros in package.xml.
2026-05-06 Enhance Lidar Sweeper Node with Calibration and Quality Control Features
    - Implemented a step-and-settle control mechanism for the LD06 2-D LiDAR to improve scan accuracy.
    - Added quality presets for scan density and speed, allowing users to choose between fast, balanced, dense, or custom settings.
    - Introduced auto-calibration functionality to measure and adjust settle time based on real-time scans.
    - Updated phase management with new states for calibration, ensuring accurate scan processing.
    - Enhanced parameter handling in the LidarSweeper class, including new parameters for hold time, scan rate, and calibration settings.
    - Modified launch files to support new parameters and improve usabi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
2026-05-06 Add lidar settle calibrator and refactor lidar sweeper
    - Introduced `lidar_settle_calibrator.py` to recommend settle time for the lidar sweeper based on servo movement and scan stability.
    - Refactored `lidar_sweeper.py` to simplify parameters and remove calibration features, focusing on step-and-settle functionality.
    - Updated launch files to reflect changes in parameters and removed unnecessary options related to calibration.
    - Removed dependency on `std_srvs` as calibration services are no longer used.
2026-05-06 Add lidar calibration launch file and update settle calibrator documentation
2026-05-07 fjernet /test_robot fra alle topics og lagt til en explor param
    [test_xacro.sdf.xacro]
2026-05-07 La til collisio avoidance node og oppdaterte de termiske nodene
    [collision_avoidance.py, thermal_converter.py, thermal_processing.py]
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2026-05-07 Endret påcollision avoidance til a bare lese GPIO og ikke SPI
    [collision_avoidance.py]
2026-05-07 imu fix try
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2026-05-07 Ryddet mye i nodene og gjorde de en del enklere + fjernet litt parametere fra launch-filen
2026-05-08 added error handling to shell command for i2c permissions in Makefile
2026-05-08 add ESP32 potentiometer reader with calibration and smoothing features
2026-05-08 Refactor lidar control: merge lidar_settle_calibrator and lidar_sweeper into unified lidar3d node
    - Deleted lidar_settle_calibrator.py and lidar_sweeper.py, merging their functionalities into lidar3d.py.
    - Updated launch files to reflect the new lidar3d node, including lidar_calibrate.launch.py and test_xacro.launch.py.
    - Adjusted parameters and topics in the launch files to accommodate the new lidar3d node structure.
    - Added python3-serial as a dependency in package.xml for UART communication.
2026-05-08 update angle offset parameter for improved accuracy in lidar3d node
2026-05-08 Add PWM chip and channel parameters for hardware PWM configuration
2026-05-08 Update PWM chip parameter to 1 for Pi 5 compatibility in lidar3d node and launch files
2026-05-08 Add unexport logic for PWM channel to prevent EBUSY errors on re-export
    [lidar3d.py]
2026-05-08 Add PWM group to container configuration in compose.yml
2026-05-08 Set 'sim' argument to False and update 'pwm_chip' parameter to 0 in lidar3d launch file
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2026-05-08 Fix angle_offset_deg parameter value in lidar3d configuration
    [lidar3d.py]
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2026-05-08 Fix formatting in Dockerfile for ros-jazzy-mola-lidar-odometry installation
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2026-05-08 Refactor URDF structure to add base_link and adjust joint definitions for consistency with MOLA requirements
    [test.urdf.xacro]
2026-05-08 Update odometry frame references to use base_link for consistency with MOLA requirements
    [test.urdf.xacro]
2026-05-08 Clarify comments regarding base_link and base_footprint relationship to prevent TF loops in URDF
    [test.urdf.xacro]
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2026-05-08 Adjust EKF frequency to 10.0 Hz and increase MOLA warmup time to 12.0 seconds for improved stability
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2026-05-08 Update RViz configuration and launch files for improved TF management and visualization
    [test.urdf.xacro]
2026-05-08 Refactor TF ownership comments for clarity and consistency in URDF
    [test.urdf.xacro]
2026-05-08 Lagt til urdf av gregor
    [Avstands-sensor-bak.stl, Avstands-sensor-fremme.stl, Avstands-sensor-høyre.stl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]
2026-05-09 Update mapping parameters and launch configurations for Gregor robot
    - Changed base frame from 'base_link' to 'base_footprint' in mapper_params_online_async.yaml for improved mapping accuracy.
    - Updated frame IDs in gregor_real.launch.py:
    - Changed LiDAR frame ID from 'LD06_LiDAR' to 'laser_link'.
    - Changed camera frame ID from 'RGB-Camera' to 'camera_link'.
    - Added a backup of the URDF file for the Gregor robot, ensuring version control and easier rollback if needed.
    [gregor.urdf]
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2026-05-09 Rename 'laser_link' to 'laser' in URDF and update launch configuration accordingly
    [gregor.urdf]
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2026-05-09 Fix URDF root reference in ekf_imu.yaml to use 'base_footprint' for clarity
2026-05-09 Update joint orientation for base_footprint to base_link connection in URDF
    [gregor.urdf]
2026-05-09 Fix joint orientation for base_footprint to base_link connection in URDF
    [gregor.urdf]
2026-05-09 Add URDF model for the 'gregor' robot
    - Created a comprehensive URDF file defining the robot structure, including links and joints.
    - Defined inertial properties, visual representations, and collision geometries for various components such as the upper level, battery, camera, and range sensors.
    - Established fixed and continuous joints to connect the robot's components, ensuring accurate representation of the robot's kinematics.
    - Included detailed specifications for each link, including mass, inertia, and mesh file paths for visual representation.
    [Gergor_rotert.urdf, gregor.urdf]
2026-05-09 Fix joint orientation for Upper-Level_Rigid-7 in URDF
    [gregor.urdf]
2026-05-09 endret msg type for å passe med collision monitor
    [collision_avoidance.py]
2026-05-09 restored to last working state
    [test.urdf.xacro]
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2026-05-09 Fix joint orientation for Upper-Level_Rigid-7 and base_footprint to base_link in URDF
    [gregor.urdf]
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2026-05-09 Change joint type of Upper-Level_Revolute-3 from continuous to fixed
    [gregor.urdf]
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2026-05-09 la til topics fra collision avoidance til nav2 collision monitor
    [collision_avoidance.py]
2026-05-09 Change IR sensor type from "ir" to "range" in collision_monitor configuration
2026-05-09 Update collision avoidance messages to use 'range' instead of 'ir' and adjust robot footprint dimensions in navigation parameters
    [collision_avoidance.py]
2026-05-09 Revert report_interval_us parameter to 40,000 in BNO085Node
    [IMU.py]
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2026-05-09 Disable front and rear IR sensors in collision_monitor due to noise issues
2026-05-10 prøvde å fikse collision monitor
    [collision_avoidance.py]
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2026-05-10 Fix map path parameter typo in ExplorationMonitor
    [exploration_monitor.py]
2026-05-10 Fix map_path and remote_target parameter values in ExplorationMonitor
    [exploration_monitor.py]
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2026-05-10 Endret max range i collision avoidance
    [collision_avoidance.py]
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
